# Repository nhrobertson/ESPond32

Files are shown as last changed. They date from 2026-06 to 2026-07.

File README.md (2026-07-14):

# ESPond32

A custom, self-hosted pond control system. An ESP32-S3 unit drives two pumps, a
water-fill valve, and a light, monitors pond water level with a float sensor, and is
controlled from a small web dashboard running on a Raspberry Pi over the local network.
It is the spiritual successor to the earlier, much simpler PondPi.

The device has no on-board web UI by design. All remote control happens over MQTT
between the firmware and the home server; the physical unit is fully functional on its
own (schedules, switches, leak lockout) even with the network down.

## System overview

```
  3-position switches          Raspberry Pi 3
  float sensor          WiFi   +-----------------------+
        |                LAN   | Mosquitto (MQTT broker)|
   +----v-----------+   <----> | espond-home-server     |  <-- browser
   | ESP32-S3 unit  |   MQTT   | (FastAPI dashboard)    |      (LAN / HTTPS)
   | (firmware)     |          +-----------------------+
   +----+-----------+
        | 3V3 GPIO
   +----v-----------+
   | SSR / relay    | ---> mains ---> pumps, valve, light
   +----------------+
```

- The firmware resolves output state from a strict precedence chain: leak lockout >
  physical switch > network override > schedule.
- The home server is the durable source of truth for configuration and schedules; the
  device only stores the last-applied config version.
- The MQTT wire contract between the two is documented in
  `software/espond-home-server/SPEC.md`.

## Repository layout

| Path | What it is |
|---|---|
| `software/espond32/` | Device firmware (ESP-IDF, C). See its README. |
| `software/espond-home-server/` | Raspberry Pi web dashboard + MQTT bridge (Python/FastAPI). See its README. |
| `hardware/` | KiCad projects (on-board and off-board SSR variants), BOMs, datasheets. See its README. |
| `ai_design_doc.pdf` | Original "Pond Control Unit — Design & Build Plan." Guidelines only; see disclosure below. |
| `LICENSE.md` | GNU GPL v3. |

## How this project was built (disclosure)

This repository mixes hand-written and AI-generated work, and it matters which is which:

- The **firmware** (`software/espond32/`) and the **hardware** (`hardware/`) were designed
  and written by hand by the project owner, with only minimal AI assistance.
- The **home server** (`software/espond-home-server/`) was generated almost entirely by an
  AI coding agent (Claude Code) working from a hand-authored spec. It has been deployed and
  works well, but should be reviewed like any AI-written code — particularly the auth and
  MQTT-handling paths — before being exposed beyond a trusted home LAN.
- `ai_design_doc.pdf` was an early planning document. It is **not** an accurate description
  of how the device actually works today; it is kept for historical context only. Where it
  conflicts with the firmware or `SPEC.md`, the firmware and `SPEC.md` win.

## Status

The off-board SSR hardware variant is finalized and in manufacturing. The firmware runs on
ESP32-S3 (developed/validated on a DevKitC). The home server is deployed on a Raspberry Pi 3.

## Safety

This system switches mains-voltage loads. Mains wiring, fusing, and enclosure work are the
integrator's responsibility. The float-fill and leak-lockout logic are failsafes, not
substitutes for correct plumbing, a hardware overflow path, and proper electrical practice.
Do not connect this to mains and water without understanding the whole chain.

## License

GNU General Public License v3. See `LICENSE.md`.

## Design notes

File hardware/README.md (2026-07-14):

# ESPond32 Hardware

KiCad projects and supporting documents for the ESPond32 control board. The board carries
the ESP32-S3-WROOM-1 module, per-channel 3-position switches, the float-sensor input, a
WS2812 status LED chain, and the output-driver stage for four channels (pump1, pump2,
valve1, light1).

Designed by hand with only minimal AI assistance.

## Two board variants

There are two KiCad projects under `kicad/`, differing only in how the mains load is
switched:

| Project | Output stage | Mains on board? | Status |
|---|---|---|---|
| `kicad/espond32-offboard-ssr/` | 3.3V/5V logic-level control signal to an **external** SSR / relay module, driven through a MOSFET buffer | No - board is entirely SELV/low-voltage | **Finalized, in manufacturing** |
| `kicad/espond32-onboard-ssr/` | On-board optotriac + power triac SSR stage, mains terminals on the PCB | Yes | Design variant / reference |

The off-board variant is the primary build. It keeps all mains wiring off the PCB (each
channel just sinks an external module's control line to ground), which greatly simplifies
safety, layout, and enclosure work. The on-board variant is kept for anyone who wants a
single-board solution and is comfortable with mains-on-PCB design; it carries fuse, MOV,
isolated AC-DC, and per-channel triac + snubber parts.

Both variants match the firmware exactly: four output channels (not three), the WS2812 LED
chain on GPIO10, and the switch/float pin map from the firmware's `config.h`.

## Folder layout

```
hardware/
  kicad/
    espond32-offboard-ssr/   # primary board - schematic, PCB, exported BOM/CPL, JLCPCB output
    espond32-onboard-ssr/    # on-board-SSR variant
  bom/                       # STALE - see below
  datasheets/                # ESP32-S3-WROOM-1 datasheet
```

## Bill of materials

**The `bom/` folder at the top level is stale. Do not order from it.** The authoritative BOM
for each board is the one exported from its KiCad project (the `.csv` files inside each
`kicad/espond32-*/` directory, and the `jlcpcb/` outputs for the off-board variant). Treat
the KiCad project as the single source of truth for parts, footprints, and designators; the
top-level `bom/` CSVs predate the current schematics and are kept only for reference.

Key part choices worth knowing before a re-spin (from the current design):

- **Module:** ESP32-S3-WROOM-1-**N8** specifically (quad flash, no PSRAM). The N8R8/N16R8
  PSRAM variants use GPIO33-37, which collide with the firmware's debug test points.
- **Off-board output stage:** logic-level N-channel MOSFET (e.g. 2N7000) per channel buffers
  the GPIO up to a full logic swing before it reaches the external SSR/relay module, so the
  design works with the widest range of off-the-shelf 3-32 VDC modules. The external SSR
  modules themselves are not part of the board BOM.
- **Switches:** one 3-position center-off (ON/AUTO/OFF) toggle per channel; common to 3V3,
  the two throws to the SW-A/SW-B GPIOs. No external pulls (firmware configures pull-downs).
- **Float input:** TVS + series resistor + RC filter, sized for a long outdoor sensor run.
- **Indicators:** a single 6-pixel WS2812B chain (pump1, pump2, valve1, light1, float, sys),
  not discrete LEDs.

## KiCad libraries

The ESP32-S3-WROOM-1 symbol/footprint come from Espressif's official KiCad library
(install via KiCad's Plugin & Content Manager). Standard passives use the built-in KiCad
libraries. A few parts (3-position switch, some connectors) use custom footprints built from
their datasheets - see the project's footprint library.

## Manufacturing (off-board variant)

The `kicad/espond32-offboard-ssr/jlcpcb/` directory holds the Gerber/BOM/CPL output prepared
for JLCPCB assembly. Regenerate it from KiCad if you change the board; do not hand-edit the
exported files.

## Safety

The off-board board is low-voltage only and safe to handle and power from USB-C or a 5V
supply. Mains switching happens entirely in the external SSR modules and their wiring
harness - fusing, strain relief, and enclosure/creepage are the integrator's responsibility.

The on-board-SSR variant puts mains on the PCB and is only for people competent with
mains-voltage design: verify fuse rating, MOV placement, isolation/creepage clearances, and
snubber sizing against your actual loads before powering it.

## Provenance and disclosure

This hardware was designed by hand with minimal AI assistance. Note that `ai_design_doc.pdf`
(repo root) is an early planning document - it specifies three output channels and discrete
indicator LEDs, whereas the shipping design has four channels and a WS2812 chain to match the
firmware. Where the design doc and the KiCad projects disagree, the KiCad projects are
correct.

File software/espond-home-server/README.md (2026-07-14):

# ESPond32 Home Server

Web control panel for the ESPond32 pond controller. Runs on a Raspberry Pi 3, talks to the
device exclusively over MQTT per `SPEC.md`, and is the durable source of truth for the
device's configuration. There is no on-device UI - this is the only dashboard.

## Provenance and disclosure

The ESPond32 **firmware** (`../espond32`) and **hardware** (`../../hardware`) were written by
hand by the project owner with minimal AI assistance. `SPEC.md` is an AI-derived contract: it
was produced by auditing the firmware's actual on-wire MQTT behavior, so it reflects what the
device really does rather than the earlier `ai_design_doc.pdf` design notes.

Everything else in this directory - the entire home server application, its tests, and its
deployment configuration - was produced **almost entirely by an AI coding agent (Claude
Code)** working from `SPEC.md`, with a human reviewing and approving the plan before
implementation but not hand-writing the code. It has been deployed and works well. Treat it
accordingly: review it (especially the auth and MQTT-handling paths) before relying on it for
anything beyond a home LAN.

## Features

- **Dashboard** - live per-output state (pump1, pump2, valve1, light1) plus the float-sensor
  reading and leak-lockout status, streamed to the browser over server-sent events.
- **Overrides** - force any output ON / AUTO / OFF (honored by the device only while its
  physical switch is in AUTO).
- **Schedule editor** - edit the daily on/off times, weekday mask, and float-sensor
  parameters, validated against `SPEC.md` before publishing.
- **Commands** - clear leak lockout, request an immediate status, reboot the device, and
  resend the current config.
- **Settings** - change the admin password and the MQTT broker connection.
- **Auth** - single admin password (bcrypt-hashed), signed session cookie, and login
  attempt lockout.

The server keeps the full config document and the last version number it pushed, and
version-increments on every change, since the device only accepts strictly-newer configs and
cannot be asked to read its config back (see `SPEC.md` §5).

## Local development

```bash
python3 -m venv .venv
.venv/bin/pip install -r requirements.txt
.venv/bin/pytest tests/           # unit tests, no broker needed
```

Run the app (needs a reachable MQTT broker - see below for a local Mosquitto, or just let it
start without one; it retries the connection in the background):

```bash
# ESPOND_COOKIE_SECURE=false is only for http:// local dev; omit it in production (Caddy/HTTPS)
ESPOND_COOKIE_SECURE=false .venv/bin/uvicorn app.main:app --reload --host 127.0.0.1 --port 8000
```

Open http://127.0.0.1:8000 - first visit prompts you to set the admin password.

### Exercising the full flow without real hardware

Run a local Mosquitto broker, then in another terminal:

```bash
.venv/bin/python tools/mock_device.py --host localhost --username espond --password password
```

`mock_device.py` plays the firmware's role (accepts config, responds to `pond/cmd`, resolves
overrides, publishes status) so you can drive the dashboard/schedule editor end-to-end. Type
`leak on`/`float on`/`reboot` at its prompt to test those states.

## Deployment (Raspberry Pi)

See `deploy/setup.sh` for a scripted bring-up (Mosquitto + this app under systemd + Caddy for
automatic HTTPS). Summary:

1. Copy this project to `/opt/espond-home-server` on the Pi.
2. `sudo bash deploy/setup.sh` - installs Mosquitto/Caddy, creates the venv, installs the
   systemd unit.
3. Point a domain/DDNS name at your home IP, edit `/etc/caddy/Caddyfile`, forward
   ports 443/80 on your router.
4. Point the ESP32 firmware's broker URI (`components/network/network.c` in the firmware
   project) at this Pi's LAN IP, with matching Mosquitto credentials.

The admin panel is reachable from the internet once port forwarding is live - that is why
setup routes everything through Caddy's automatic HTTPS rather than serving plain HTTP.

## Configuration

Broker host/port/credentials are stored in the database and editable at `/settings`; the
`ESPOND_MQTT_*` environment variables only seed the defaults on first run. Other environment
variables: `ESPOND_DB_PATH`, `ESPOND_SESSION_MAX_AGE`, `ESPOND_COOKIE_SECURE`.

## Project layout

- `app/` - FastAPI application
  - `mqtt_client.py` - MQTT wire-contract implementation (publish config/override/cmd, parse status)
  - `routes/` - dashboard, schedule, settings, auth, and the SSE `events` stream
  - `state.py` - in-memory device state fed from `pond/status` / `pond/availability`
  - `validators.py` - `SPEC.md` §3 payload validation
  - `db.py`, `models.py`, `auth.py`, `settings.py` - storage, schemas, auth, config
  - `templates/`, `static/` - server-rendered UI
- `deploy/` - systemd unit, Mosquitto config, Caddyfile, bring-up script
- `tools/mock_device.py` - firmware simulator for local testing
- `tests/` - unit tests (validators, MQTT payload shapes, auth)
- `SPEC.md` - authoritative MQTT wire contract (source of truth over `ai_design_doc.pdf`)

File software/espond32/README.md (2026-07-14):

# ESPond32 Firmware

Firmware for the ESPond32 pond control unit. Targets the **ESP32-S3-WROOM-1 (N8)** and
builds as a standard ESP-IDF project. It drives two pumps, a water-fill valve, and a light
through external solid-state relays, monitors pond level with a float sensor, and is
controlled remotely over MQTT by the home server (`../espond-home-server`).

Written by hand in C with only minimal AI assistance used for minor debugging and heavy review. Committed under the GNU GPL v3.

## What it does

- Runs each output (pump1, pump2, valve1, light1) on a weekday-aware daily schedule.
- Resolves the real output state through a fixed precedence chain (highest wins):
  1. **Leak lockout** - forces pumps and valve off; survives reboot (persisted in NVS).
  2. **Physical 3-position switch** - ON / AUTO / OFF per channel; a thrown switch beats
     any network override.
  3. **Network override** - `pond/override` from the server, honored only while the switch
     is in AUTO.
  4. **Schedule** - the configured on/off/days, honored only when switch and override are
     both AUTO.
- Automatically fills the pond via `valve1` when the float sensor reads dry, with a
  configurable arming debounce and overflow timeout, and a daily fill-count cap.
- Engages leak lockout when the pond fills too many times in a day or a single fill runs
  too long (stuck-float failsafe), and requires an explicit clear (server command or a 5s
  physical reset-button hold) to recover.
- Reports state to the server over MQTT and drives a WS2812 status LED chain.

Precedence and float behavior are the safety-critical parts of the design and are the
reason there is no on-device web UI: the unit keeps running correctly with the network down.

## Architecture

Devices are unified behind a small polymorphic interface (`device_t` / `device_ops_t`) so
pumps, valve, light, and the float sensor share one code path. Work is split across
FreeRTOS tasks pinned to the two cores:

| Task | Core | Cadence | Role |
|---|---|---|---|
| `task_check_io` | 1 | 10 ms | Debounce switches + float sensor |
| `task_evaluate_cfg` | 1 | 250 ms | Resolve schedule/override/lockout precedence |
| `task_operate` | 1 | 50 ms | Apply resolved state to SSR GPIOs |
| `task_check_leak` | 1 | 10 ms | Float-fill state machine + leak detection |
| `task_check_for_reset` | 1 | 50 ms | Reset-button hold detection |
| `task_listen_for_task_event` | 1 | event | Handle clear-leak / command events |
| `task_set_sys_light` | 1 | 1 s | System status LED |
| `task_check_cfg` | 0 | event | Apply new config (double-buffered swap) |
| `task_net_manager` | 0 | event | WiFi + MQTT lifecycle |

Config is double-buffered: the MQTT task writes into a staging buffer, and `task_check_cfg`
atomically swaps it into the live config under a mutex. Config is version-gated and
persisted to NVS, so it survives reboots and only newer versions are applied.

### Components

| Component | Responsibility |
|---|---|
| `config/` | Pin map, device counts, timing constants, debug GPIOs |
| `models/` | Shared types, enums, JSON builders, RTOS handles |
| `device/` | Device abstraction + state resolution |
| `io/` | GPIO configure/set, software debounce, reset button |
| `float/` | Float-fill state machine and leak logic |
| `led/` | WS2812 status LED driver |
| `date_and_time/` | SNTP time + schedule evaluation (handles overnight wrap) |
| `filesystem/` | NVS persistence (config version, leak lockout) |
| `network/` | WiFi STA, MQTT client, config parse, status publish |
| `tasks/` | The FreeRTOS task bodies listed above |

## Pin map

Defined in `components/config/include/config.h`. Each output uses two switch inputs plus one
SSR output; the float sensor is a single input; one GPIO drives the WS2812 chain.

| Function | GPIO |
|---|---|
| Pump1 SSR / SW-A / SW-B | 4 / 5 / 6 |
| Pump2 SSR / SW-A / SW-B | 7 / 15 / 16 |
| Valve1 SSR / SW-A / SW-B | 17 / 18 / 8 |
| Light1 SSR / SW-A / SW-B | 11 / 12 / 13 |
| Float sensor | 9 |
| WS2812 data | 10 |
| Reset / leak-clear button | 14 |

GPIO35-38 are used as task-timing debug test points (`DEBUG_GPIO_*`), which is why the
module **must** be the N8 (no-PSRAM) variant - the PSRAM variants use those pins internally.
The switch inputs are configured pull-down and the reset button pull-up, so no external pull
resistors are needed.

## MQTT interface

The device connects to one broker and speaks the contract in
`../espond-home-server/SPEC.md`. Summary of topics:

| Topic | Direction | Purpose |
|---|---|---|
| `pond/config` | server -> device | Full config (version-gated, all 4 outputs + float params) |
| `pond/override` | server -> device | Force a single output ON/AUTO/OFF |
| `pond/cmd` | server -> device | `clear_leak_lockout` / `reboot` / `request_status` |
| `pond/status` | device -> server | Retained state of all 4 outputs + float reading |
| `pond/availability` | device -> server | Retained `online`/`offline` (MQTT Last-Will) |

Single-device assumption: topics are fixed global strings, not namespaced per unit.

## Build and flash

Requires ESP-IDF (v4.1+; developed on a recent v5.x). Managed components (`led_strip`,
`cjson`, `mqtt`) resolve automatically via the component manager.

```bash
idf.py set-target esp32s3
idf.py build
idf.py -p /dev/ttyACM0 flash monitor
```

## Configuration you must change before flashing (disclosure)

`components/network/network.c` currently contains **hardcoded placeholder credentials** that
need to be replaced for your environment before deployment:

- WiFi SSID and password.
- MQTT broker URI (point it at your Raspberry Pi / Mosquitto LAN IP).
- MQTT client id / username / password (must match the broker's credentials).

MQTT is plaintext (no TLS) and the broker auth is a single username/password. This is
acceptable for a trusted home LAN but should be hardened before the device is reachable from
anywhere less trusted. Do not commit real WiFi/broker secrets.

## Provenance and disclosure

- This firmware was written by hand; AI assistance was minimal.
- `IMPLEMENTATION_STATUS.md` in this directory is a **historical AI-generated audit** from an
  earlier revision. It documented bugs that were subsequently addressed and does not describe
  the current state of the code - read it as a snapshot, not as current documentation.
- `SPEC.md` (in the home-server directory) was derived by auditing this firmware's actual
  on-wire behavior, so it reflects what the device really does. The older `ai_design_doc.pdf`
  is guidelines only and is superseded wherever it conflicts.

## License

GNU General Public License v3. See `../../LICENSE.md`.

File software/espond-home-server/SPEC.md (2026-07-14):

# ESPond32 Home Server — Network Interaction Spec

Version 0.1 — derived directly from the current ESPond32 firmware (`../espond32`), not from
`ai_design_doc.pdf`. The firmware's actual on-wire behavior is now the source of truth for this
contract; the design doc's original §8/§9 examples (weekday-string `days`, `"id"`-keyed outputs,
a `"float"` config key) are superseded and should be ignored where they conflict with this
document.

This spec covers only the **network interaction contract** between the home server and one
ESPond32 unit. It does not cover the server's own UI, storage schema, or scheduling algorithms —
those are implementation details of the home server itself.

## 1. Scope & deployment target

- The home server is a service intended to run on a **Raspberry Pi 3**, reached over the same
  **WiFi LAN** as the ESPond32 device. No wired/Ethernet assumption.
- All device interaction happens over **MQTT**. There is no HTTP/REST/webpage on the device
  itself (the design doc explicitly rejected an on-device web UI in favor of MQTT + a home
  server).
- The firmware connects to a single hardcoded broker URI (`network.c`: `mqtt_cfg.broker.address.uri`,
  currently the placeholder `"mqtt://IP_ADDR"`). **Something has to run a broker** (e.g.
  Mosquitto) reachable at that address. The simplest deployment is to run the broker on the same
  Raspberry Pi as the home server and point the firmware's placeholder URI at the Pi's LAN IP —
  but this is a deployment decision, not something the firmware enforces.
- MQTT is currently **plaintext, unauthenticated at the broker level** beyond a username/password
  pair (`network.c`: client id `"espondcu"`, username `"espond"`, password `"password"` — all
  placeholders). No TLS. The home server should use the same broker credentials scheme; treat
  this as "expected to be hardened later," not something to over-engineer around today.
- **Single-device assumption.** Every topic below is a fixed global string (`pond/...`), not
  namespaced by device ID. The firmware does not support multiple ESPond32 units sharing one
  broker without a firmware change (topic namespacing). Build the server for exactly one device
  for now.

## 2. Topics

| Topic | Direction | QoS | Retained | Payload |
|---|---|---|---|---|
| `pond/config` | server → device | 1 | no | JSON, §3.1 |
| `pond/cmd` | server → device | 1 | no | raw string, §3.2 |
| `pond/override` | server → device | 1 | no | JSON, §3.3 |
| `pond/status` | device → server | 1 | **yes** | JSON, §3.4 |
| `pond/availability` | device → server | 1 | **yes** | `"online"` / `"offline"` (LWT), §3.5 |

The device subscribes to the first three on every MQTT connect and does not persist an MQTT
session across reconnects — the server should assume a fresh subscribe happens each time the
device reconnects, and should be prepared to re-deliver `pond/config` if it suspects the device
missed it (see §6).

## 3. Message schemas

### 3.1 `pond/config` (server → device)

```json
{
  "version": 4,
  "outputs": [
    { "name": "pump1",  "on": "14:00", "off": "14:05", "days": [0,1,2,3,4,5,6] },
    { "name": "pump2",  "on": "14:00", "off": "14:05", "days": [0,1,2,3,4,5,6] },
    { "name": "valve1", "on": null,    "off": null,    "days": [] },
    { "name": "light1", "on": "18:00", "off": "23:00", "days": [5,6] }
  ],
  "float_sens": { "threshold_min": 10, "overflow_min": 30, "max_fills_per_day": 3 }
}
```

Field rules (enforced by `parse_config_json` — any violation causes the **entire message to be
rejected**, with no partial apply and no error reported back to the server over MQTT):

- `version`: integer. The device only accepts a config if `version` is **strictly greater** than
  its currently stored version (persisted in NVS, survives reboot). The server must track the
  last version it successfully pushed and always increment before pushing a change. There is no
  way to query the device's currently-applied version except via `pond/status` (see §3.4) —
  the server is the source of truth for "what config is on the device," not the other way around
  (see §6, known limitation).
- `outputs`: array, up to 4 entries. Each entry is matched **by `"name"`, not position or an
  `"id"` field** — must be exactly one of `"pump1"`, `"pump2"`, `"valve1"`, `"light1"`. Unknown
  names are rejected (whole message fails). If an expected device name is *missing* from the
  array, that device silently keeps a fully-off, never-scheduled state — the firmware treats an
  absent entry as "no schedule" rather than erroring, so a partial `outputs` array won't crash
  anything, but it also won't preserve whatever schedule was previously set for the omitted
  device. Always send all 4 entries.
- `on` / `off`: `"HH:MM"` 24-hour strings, or both `null` together to mean "no schedule" (device
  only reachable via `pond/override` or the physical switch, never turns on by schedule).
  Sending only one of the two as `null` is invalid and rejects the message.
- `days`: array of integers **0–6** (Sunday=0 through Saturday=6, matching C `tm_wday` — **not**
  weekday abbreviation strings). Empty array is valid (means "no day is scheduled," equivalent in
  effect to a null on/off). Any value outside 0–6 rejects the whole message.
- `float_sens.threshold_min`: minutes the float sensor must continuously read "low" (float out
  of the water) before the device treats it as a genuine low level and opens `valve1` to fill
  (debounces brief dips from waves/ripples). Note the sensor polarity: the float line idles high
  and closes to ground when the float is submerged, so `pond/status` reports `float1.state=true`
  when the water is **low / a fill is wanted**, not when it is wet — see §3.4.
- `float_sens.overflow_min`: minutes after the sensor reads "not low" again (float back in the
  water) before the fill is considered fully finished (closes out the fill cycle / daily fill
  count).
- `float_sens.max_fills_per_day`: if the number of completed fill cycles in the current calendar
  day exceeds this, the device engages **leak lockout** (see §4) — forces `pump1`, `pump2`, and
  `valve1` off regardless of schedule or override, until explicitly cleared.

There is no partial-update semantics — every push must include the full desired state for all
4 outputs and all 3 float-sensor parameters. The server should keep this full config resident and
always send a complete document.

### 3.2 `pond/cmd` (server → device)

Plain string payload, **not JSON**. Exactly one of:

| Payload | Effect |
|---|---|
| `clear_leak_lockout` | Clears leak lockout: resets `lockout` state (RAM + NVS) and the daily fill counter. Devices return to normal schedule/override/switch resolution on the next evaluate cycle (≤250ms). |
| `reboot` | Immediate `esp_restart()`. No graceful shutdown, no ack. |
| `request_status` | Forces an immediate `pond/status` publish (see §3.4), independent of whether anything changed. |

Any other string is silently ignored — no error is published back.

### 3.3 `pond/override` (server → device)

```json
{ "name": "pump1", "override": 0 }
```

- `name`: one of `"pump1"`, `"pump2"`, `"valve1"`, `"light1"`. `"float1"` is rejected — the float
  sensor is input-only and cannot be overridden.
- `override`: integer, one of:

  | Value | Meaning |
  |---|---|
  | `0` | Force **ON** |
  | `1` | Release to **AUTO** (schedule decides) |
  | `2` | Force **OFF** |

  Any other integer is accepted by the parser but silently treated as `1` (AUTO) — there is no
  rejection for an out-of-range override value, unlike the other message types.

An override only takes effect while that device's **physical 3-position switch is in the AUTO
position** — see precedence in §4. There is no way to know from the network side alone whether an
override is currently "winning" versus being shadowed by the physical switch; `pond/status`
reports the resulting `state` (on/off) but not *why* it's in that state.

### 3.4 `pond/status` (device → server, retained)

```json
{
  "version": 4,
  "leak_lockout": false,
  "outputs": [
    { "name": "pump1",  "state": true },
    { "name": "pump2",  "state": false },
    { "name": "valve1", "state": false },
    { "name": "light1", "state": true },
    { "name": "float1", "state": false }
  ]
}
```

- Despite the key being `"outputs"`, this array always has **5** entries, not 4 — `"float1"` is
  included and its `"state"` is an input reading, not an output being driven. `float1.state=true`
  means the **float is out of the water (level LOW, a fill is wanted)**; `false` means the water
  is up. This follows the firmware's sensor polarity (idle-high line pulled to ground when the
  float is submerged) — do not read `true` as "wet." The server must not treat all 5 entries
  uniformly if it plans to expose actuator-only controls.
- `"state"` is the *actual* on/off/active state after all precedence resolution (leak lockout,
  switch, override, schedule) — it is the only place the server can observe the real-world
  outcome of a config or override push.
- Published only when something changes (a device's on/off state flips, leak lockout engages) or
  when explicitly requested via `pond/cmd` → `request_status`. **It is not published on a
  periodic heartbeat**, and it is not automatically (re-)published just because the server
  reconnects to the broker — only the *retained* copy from the last publish is delivered on
  subscribe. If the server needs current truth right after startup/reconnect, send
  `request_status` rather than trusting the retained value blindly (the device could have
  rebooted, or its state could have changed while the broker was unreachable to the retained
  message... though MQTT retained messages do survive broker restarts if persistence is enabled -
  the risk is specifically a *device*-side change with no observer connected to receive it live).

### 3.5 `pond/availability` (device → server, retained, Last Will)

Payload is the literal string `"online"` (published once, on every successful MQTT connect) or
`"offline"` (published automatically **by the broker**, not the device, as the MQTT Last-Will
message if the device disconnects without a clean shutdown — e.g. power loss, WiFi drop, crash).
The server should treat `"offline"` (or the topic simply never having been set) as "device
presence unknown," and should not assume the device's last known `pond/status` is still accurate
once availability drops to offline.

## 4. Precedence model the server must respect

For `pump1`, `pump2`, `valve1` (light1 is the same minus the lockout tier):

1. **Leak lockout** (if engaged) — forces OFF. Beats everything, including a manual override.
   Only `pond/cmd` → `clear_leak_lockout`, or a 5-second physical reset-button hold on the
   device, can lift it.
2. **Physical 3-position switch** — if held to the ON or OFF side (not centered/AUTO), that wins
   over any `pond/override` sent by the server. The server has no way to detect switch position
   directly; it can only infer "my override doesn't seem to be taking effect" from `pond/status`
   not matching what was requested.
3. **`pond/override`** (server command) — only consulted when the switch is centered/AUTO.
4. **Schedule** (`pond/config` on/off/days) — only consulted when both switch and override are
   AUTO.

Implication for the server: don't build a UI that assumes a command always "wins" — always treat
`pond/status` as the arbiter of truth, and design any "why didn't my change apply" UX around the
possibility of the physical switch overriding it silently.

## 5. Known limitations / open items for the server design

- **No config read-back.** The device cannot be asked "what config do you currently have
  applied?" beyond the bare `version` number in `pond/status`. The server must be the durable
  store of the full config document and must not assume it can reconstruct it from the device.
- **No per-command acknowledgment.** Every `pond/cmd`/`pond/override`/`pond/config` message is
  fire-and-forget; success or failure is only observable indirectly through a later
  `pond/status` change (or its absence).
- **No malformed-message feedback.** A rejected `pond/config` (bad version, bad name, out-of-range
  day, etc.) fails silently on the device side — no error topic, no NACK. The server should
  validate against §3.1's rules itself before publishing, since the device won't tell it what
  went wrong.
- **Single device, unauthenticated broker, plaintext transport** — acceptable for a bench/home
  LAN today; flag before this is ever exposed beyond a trusted local network.
- **Broker location is undecided** — this spec assumes *a* broker exists at whatever URI the
  firmware is flashed with; deciding whether that's Mosquitto on the same Pi as the server or a
  separate box is a deployment decision for whoever sets up the Pi, not a firmware or server
  constraint.

## 6. Suggested server responsibilities (non-normative)

Not part of the wire contract, but worth the server implementation keeping in mind:

- Persist the full last-pushed `espond_cfg_t`-equivalent document and the last version number
  used, so a server restart doesn't lose track of what's supposedly on the device.
- On startup / broker reconnect, subscribe to `pond/status` and `pond/availability`, then send
  `request_status` once availability shows `"online"`, rather than trusting a stale retained
  status.
- Treat `pond/status`'s 5-entry array as the single source of "what is actually happening right
  now" for any dashboard, rather than mirroring back whatever config/override was last sent.

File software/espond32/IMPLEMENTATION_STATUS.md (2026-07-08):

# ESPond32 — Implementation Status Evaluation

_Evaluation of firmware vs. the design doc (`../../ai_design_doc.pdf`, "Pond Control Unit — Design & Build Plan"). Date: 2026-07-07. No code was modified to produce this — full read-through of every `.c`/`.h` file in `main/` and `components/`._

## Overall status

The architecture and most of the parsing/scheduling logic are well-reasoned and track the design doc closely: a device abstraction unifying pumps/valve/light/float behind one polymorphic `device_ops_t` interface, FreeRTOS tasks that split cleanly along the doc's lines (input check / config apply / schedule+precedence resolve / operate / leak / net), NVS-backed JSON config with version gating, and an MQTT sync layer with retained topics and Last-Will.

That said, **this is not "almost done."** A full read of every source file turned up several bugs that would prevent correct operation if flashed today — including bugs very likely to crash on first boot, and one that defeats the design doc's single most important correctness rule (leak lockout must force outputs off). This reads as **mid-Phase-3/4 firmware in progress**, not a working autonomous controller. The hardware/PCB (design doc phases 6–10), home server (phase 11), and enclosure (phase 12) are entirely out of scope for this repo and not evaluated here.

## Firmware, phase by phase (design doc §14)

| Phase | Status | Notes |
|---|---|---|
| 0 — Toolchain | Done | ESP-IDF project targets `esp32s3`; managed components (cJSON, esp-mqtt, led_strip) resolve; project builds as a normal IDF tree. |
| 1 — Bare I/O | Mostly done | GPIO configure/read/set, majority-count software debounce, and the WS2812 LED driver init all exist and are structurally sound — but see LED bug below: nothing is ever actually pushed to the physical strip. |
| 2 — Timekeeping | Mostly done | SNTP is started and a timezone (`EST5EDT,M3.2.0,M11.1.0`) is set in `network.c`, addressing the exact drift bug the redesign was meant to fix. `get_local_time()` exists and is used by both the scheduler and the leak/float logic. No DS3231/RTC (called out as optional in the doc). |
| 3 — Scheduler + Output manager | Implemented, but the safety-critical path is broken | `evaluate_device_schedule()` correctly handles overnight wraparound and per-weekday masking. `resolve_device_state()` implements the switch/override precedence. **But** the leak-lockout tier silently disables the entire resolver instead of forcing outputs off — see Critical Bug #2. |
| 4 — Float-fill + leak | Implemented, with two logic bugs | State machine (idle → arming → filling → overflow) exists and daily fill counting/latching exists, but the configurable `threshold_min` debounce is never applied (Critical Bug #6) and the MQTT "clear leak lockout" command doesn't actually clear the lockout (Critical Bug #7). |
| 5 — Connectivity | Implemented, least-hardened area | WiFi STA, MQTT with Last-Will, version-gated config → NVS persistence, exponential backoff reconnect, and status publishing all exist. Credentials are still hardcoded placeholders (`"ssid"`, `mqtt://IP_ADDR`) and MQTT is plaintext — expected at this stage. `publish_status` has a memory-corruption bug (Critical Bug #5). |

## Critical bugs (would misbehave or crash on real hardware)

4. **`parse_override_json` corrupts memory and copies the wrong field.** `components/models/models.c:128`:
   ```c
   override_json_t over = { .name = "", .override = OVR_AUTO };
   ...
   strcpy(over.name, name->string);
   ```
   `override_json_t.name` is a `char*` (`models.h:142`) initialized to point at a string literal — `strcpy` into that writes to read-only memory. It also copies `name->string` (the JSON *key*, literally the text `"name"`) instead of `name->valuestring` (the actual device name sent by the server). Any incoming `pond/override` MQTT message will corrupt memory / likely crash, and even if it didn't, would never match a real device name.

5. **`publish_status` has the same class of bug.** `components/network/network.c:165`: `strcpy(devices[i].name, g_devices[i].name)` writes into `devices[i].name`, an uninitialized stack `char*` (`status_json_builder_t.name` is a pointer, not a fixed buffer — `models.h:138`). This runs on every status publish and is effectively guaranteed stack corruption. `g_devices[i].name` should be used directly in the `sniprintf` call below it; the intermediate copy is both unnecessary and broken.

6. **`threshold_min` is parsed but never used — the float-fill "wait before triggering" delay is a no-op.** `eval_float_state` (`components/float/float.c:39`):
   ```c
   case (FILL_IDLE):
     if (active) {
       float_deadline_us = time_us;      // should be time_us + minutes_us(threshold_min)
       dev->u.in.state = FILL_ARMING;
     }
   ```
   The deadline is set to *now*, so on the very next evaluation `time_us >= float_deadline_us` is already true and the valve fires immediately. The configurable debounce period from design-doc §2/§8 (and preserved intentionally from the original PondPi) currently does nothing.

7. **The MQTT "clear leak lockout" command doesn't clear the lockout.** `handle_command_msg` → `task_listen_for_task_event` → `clear_leak()` only resets the daily fill counter (`float.c:11`); it never resets the `lockout` bool or the forced `OVR_OFF` overrides that `task_check_leak` applied. Only the physical 5-second reset-button hold (`tasks.c:39-41`, which also `esp_restart()`s the device) actually clears it. The server-facing command described in design-doc §9 is effectively dead.

8. **Leak lockout state is written to NVS but never read back.** `nvs_set_lockout`/`nvs_clear_lockout` (`components/filesystem/filesystem.c`) persist a `"lockout"` key, but nothing in the tree ever calls `nvs_get_u8` for it — `lockout` always starts `false` on boot regardless of what was persisted before a reset, defeating the point of persisting it. (Partially masked by Bug #2's frozen-state behavior, but the intent — a lockout that survives a power cycle — is broken either way.)

## Secondary issues

- **GPIO interrupts configured but never wired up.** Switches and the float sensor are configured with `GPIO_INTR_HIGH_LEVEL`, and the reset button with `GPIO_INTR_ANYEDGE` (`components/io/io.c:30,104,107,114`), and interrupts are enabled via `gpio_intr_enable` — but `gpio_install_isr_service`/`gpio_isr_handler_add` are never called anywhere. Everything actually works today via 10 ms polling in `task_check_io`, so this is at minimum dead configuration; a level-triggered interrupt enabled with no ISR to service/clear it is also the kind of thing that can trip the interrupt watchdog on real silicon. Either remove it or wire it up properly.
- **`PIX_BLUE` is defined as green.** `components/led/led.c:8`: `const pix_t PIX_BLUE = {.r=0, .g=255, .b=0};` — identical to `PIX_GREEN`. The float-active indicator (`tasks.c:216` uses `PIX_BLUE`) would show green, not blue, once Bug #3 is fixed.
- **`nvs_flash_init()`'s return value is discarded** (`main/espond32.c:41`) — no erase+retry on `ESP_ERR_NVS_NO_FREE_PAGES`/`ESP_ERR_NVS_NEW_VERSION_FOUND`, a common real-world case after reflashing with a different partition layout. A corrupted NVS partition would currently, silently and permanently, prevent config persistence with no self-healing path.
- Dead/unfinished abstractions: `led_state_t` / `get_color()` (declared `static` in `led.h`, never defined or used — LED updates go through raw `pix_t` colors instead of the state machine the types imply); `io_operate()` declared in `io.h` but never defined; `nvs_load_espond_cfg` is file-internal but not marked `static`.
- `#define NUM_LEDS NUM_DEVICES + 2` (`components/config/include/config.h:14`) is unparenthesized — harmless today (only used standalone) but a latent bug if it's ever combined with an operator at a use site.
- Hardcoded placeholder WiFi/MQTT credentials and plaintext (non-TLS) MQTT in `network.c` — expected at this stage, flagged only so it isn't forgotten before anything leaves the bench.

## What's solid

- The `device_t`/`device_ops_t` polymorphic abstraction cleanly unifies pumps/valve/light/float behind one interface and matches the design doc's intent well.
- `evaluate_device_schedule()` (`date_and_time.c`) correctly handles overnight (`on_min > off_min`) wraparound schedules and per-weekday masking — genuinely correct logic.
- `parse_config_json()` is careful and defensive: `goto cleanup` on every malformed field, `strlcpy` for names, explicit range checks in `parse_hhmm`.
- The debounce implementation in `io.c` is a reasonable simple majority-count debounce.
- The MQTT topic layout (`pond/config`, `pond/status`, `pond/availability`, `pond/cmd`, plus an added `pond/override` not in the doc) matches design-doc §9 closely, with retained messages and Last-Will wired correctly.
- Config double-buffering (`g_buff_cfg` written by the MQTT task, atomically swapped into `g_espond_cfg` under `cfg_change_mutex` by `task_check_cfg`) is a sound pattern for cross-core, cross-task config updates.

## Bottom line

The plumbing and the "shape" of the system are close to the design doc and mostly well-structured. But between a near-certain boot-time crash (Bug #1), two memory-corruption bugs on incoming/outgoing MQTT traffic (Bugs #4, #5), a dead LED subsystem (Bug #3), and — most importantly — a leak lockout that doesn't actually cut power (Bug #2), this needs a focused debugging pass before it's safe to move on to phase 6 (prototype circuit) or trust it near mains and water at all.

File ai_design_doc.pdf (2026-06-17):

# Pond Control Unit

## An ESP32-S3 reimagining of PondPi — design & build plan

A from-scratch redesign of a backyard-pond pump and water-fill controller. The unit runs autonomous scheduling firmware on an ESP32-S3 under ESP-IDF, is configured from a separate home-server admin panel, and is built around a single integrated PCB that brings mains power, isolated logic, and three on-board triac solid-state-relay channels onto one board.

Design document · synthesized from project planning
Original concept: PondPi by Noah Robertson (MIT) · github.com/nhrobertson/PondPi
Pond Control Unit — Design & Build Plan | Page 1 of 20

## Contents

### 1. Overview

### 2. Background: the original PondPi

### 3. Design decisions

### 4. System architecture

### 5. Hardware requirements

### 6. Firmware architecture

### 7. Output precedence logic

### 8. Configuration model

### 9. Sync protocol & timekeeping

### 10. ESP-IDF project structure

### 11. Home server

### 12. PCB design

### 13. Indicative bill of materials

### 14. Plan of attack

### 15. Safety notice

### 16. Appendix: pin budget & references

## 1 Overview

The Pond Control Unit (PCU) controls two pond pumps and an automatic water-fill valve, with a float sensor for level detection. It replaces the Raspberry Pi Pico W at the heart of the original PondPi project with an ESP32-S3, and splits the system into three tiers: an admin browser, a home server that hosts the configuration panel, and the edge device that does the actual switching.

The defining principle of this redesign is device autonomy. The home server is where schedules are edited, but the ESP32 stores its own copy of the configuration and runs it independently. If the server reboots, the network drops, or the internet is unavailable, the pumps keep running on schedule. The server pushes configuration down; the device reports status up.

The four functional signals are unchanged from the original requirements:

Float sensor — optional 3.3 V input plus an indicator LED.
Pump 1 — 3.3 V output driving an SSR that switches a 120 V pump, plus an LED.
Pump 2 — as Pump 1.
Water fill — 3.3 V output driving an SSR that switches a 120 V electric valve, plus an LED.

Every output additionally has a physical switch that enables or disables that function, and every output has its own LED indicator.

## 2 Background: the original PondPi

PondPi is a single Raspberry Pi Pico W running MicroPython that does everything on one device. Understanding its structure clarifies exactly what is being kept, changed, and fixed.

Module | Role
main.py | Async entry point; initializes timers, loads the web page, connects WiFi, starts the HTTP server and the float/leak monitor tasks.
hw_util.py | GPIO control (outputs on pins 3/4/5, float sensor on pin 18), float-fill logic, leak detection, timer setup.
timer.py | A Timer class that checks every 60 s whether the current hour/minute/day matches and fires a callback.
config_manager.py | Reads/writes an INI-style config.txt for persistence.
network_util.py | WiFi connect and a hand-rolled HTTP server that parses requests and dispatches to enable/disable/set-time handlers.
index.html | The web UI served directly by the device.

Its float logic is worth preserving: when the float sensor stays active past a configurable threshold time, the water-fill output turns on; when the sensor clears, the fill stays on for an overflow time, then shuts off. A leak guard counts fills per day and latches everything off if more than a set number occur in 24 hours, requiring

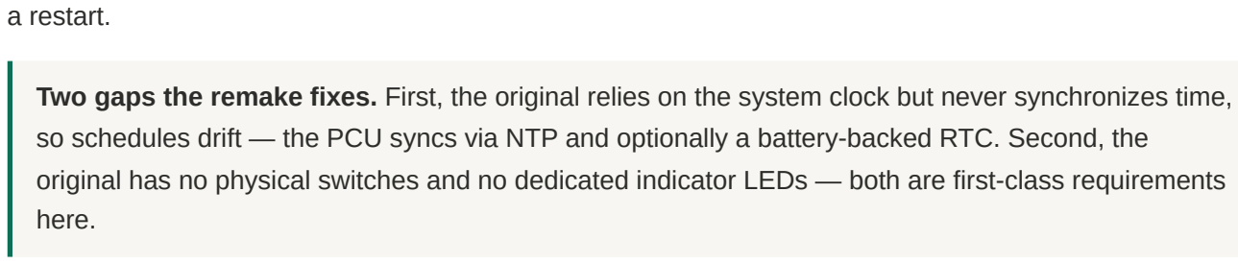
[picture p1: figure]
a restart.; here.

Two gaps the remake fixes. First, the original relies on the system clock but never synchronizes time, so schedules drift — the PCU syncs via NTP and optionally a battery-backed RTC. Second, the original has no physical switches and no dedicated indicator LEDs — both are first-class requirements

## 3 Design decisions

The following choices were made up front; they shape every later section.

Decision | Choice | Rationale
Goal | Fully custom build | Maximum control and learning value; not a low-code/Home-Assistant path.
Firmware stack | ESP-IDF (C) | Native FreeRTOS, fine-grained control of tasks, NVS, drivers, and OTA.
Device autonomy | Autonomous | Device stores and runs its own schedule; survives server/network outages.
Board power | Isolated AC-DC on board | Single mains feed; fully integrated unit. Raises isolation/layout requirements.
Load switching | On-board triac SSRs (opto-triac + triac) | Compact, cheap, true solid-state switching built from discrete parts.
MCU | ESP32-S3 module | Native USB for flashing/JTAG, ample flash/PSRAM, pre-certified RF module.

## 4 System architecture

The system is three tiers. An admin browser talks to the home server over HTTP. The home server syncs configuration and status with the ESP32 over WiFi. The ESP32 reads 3.3 V inputs and drives 3.3 V outputs into solid-state relays that switch the 120 V loads.

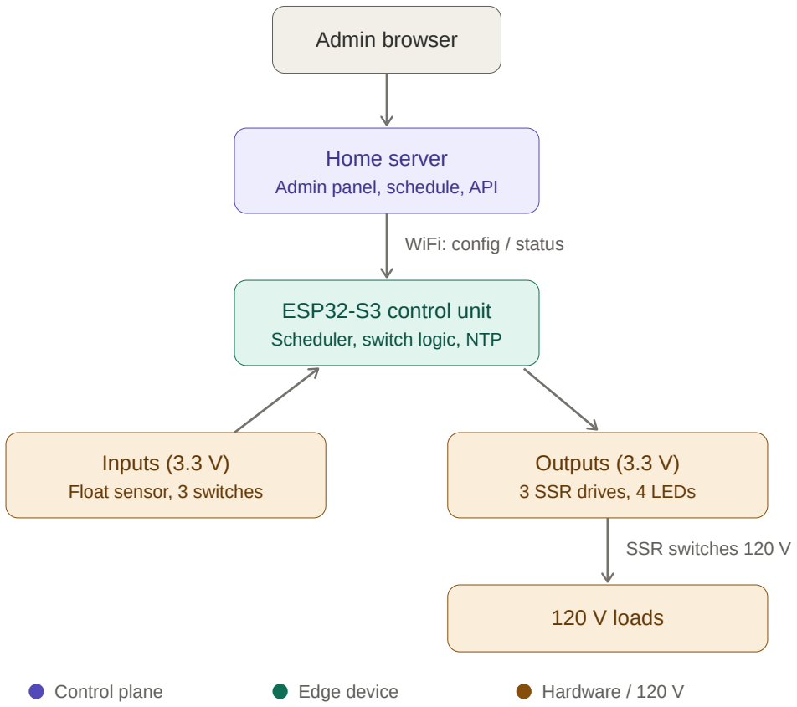
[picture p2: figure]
Admin browser; Home server; Admin panel, schedule, API; WiFi: config / status; ESP32-S3 control unit; Scheduler, switch logic, NTP; Inputs (3.3 V); Float sensor, 3 switches; Outputs (3.3 V); 3 SSR drives, 4 LEDs; SSR switches 120 V; 120 V loads; Control plane; Edge device; Hardware / 120 V

Figure 1 — Three-tier system architecture.

This separates concerns cleanly: the home server owns the human-facing editing experience, while the device owns execution. The only thing crossing the WiFi link is a small configuration blob in one direction and status in the other.

## 5 Hardware requirements

The I/O budget is small — roughly eleven GPIO — so any ESP32 variant suffices; the S3 is chosen for native USB and headroom. The signal set:

Signal | Direction | Notes
Float sensor | Input | Internal pull, software debounce, TVS + series resistor for the long outdoor run.
Switch 1 / 2 / 3 | Input | One 3-position switch per output: ON / OFF / AUTO .
SSR drive 1 / 2 / 3 | Output | 3.3 V logic into the opto-triac LED of each channel.
LED 1 / 2 / 3 | Output | Output-state indicators, driven on the logic side.
Float LED | Output | Sensor-active indicator.

Three-position switches

Rather than a plain on/off toggle, each output gets a 3-position switch. OFF forces the output off (a true safety lockout), ON forces it on (manual override), and AUTO hands control to the firmware schedule. The firmware reads the switch position and always honors it; the indicator LED reflects the resolved state so the panel never lies about what a load is actually doing. For a hardware-level guarantee, the OFF position can additionally interrupt the SSR control line so that a firmware fault cannot override a lockout.

## 6 Firmware architecture

The firmware is a set of cooperating FreeRTOS tasks. Because the device is autonomous, the schedule lives in non-volatile storage (NVS) and runs with or without the network.

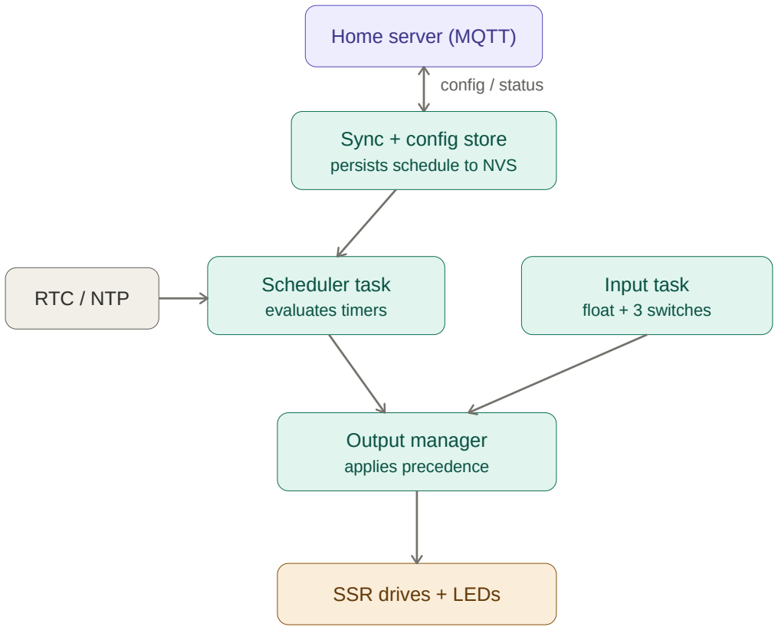
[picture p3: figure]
Home server (MQTT); config / status; Sync + config store; persists schedule to NVS; RTC / NTP; Scheduler task; evaluates timers; Input task; float + 3 switches; Output manager; applies precedence; SSR drives + LEDs

Figure 2 — FreeRTOS task and data flow inside the autonomous firmware.

Task | Responsibility
Sync + config store | Receives configuration over MQTT, validates it, and persists it to NVS. Notifies the scheduler to reload.
Scheduler | Wakes roughly once a minute, compares each output's on/off timer and active days against the RTC, and sets the desired AUTO state.
Input task | Debounces the float sensor and reads the three switch positions; raises events for the output manager.
Output manager | Resolves every output through the precedence rules below and drives the SSR control lines and indicator LEDs. Also owns the float-fill and leak logic.

Shared state (the live configuration and resolved output states) is guarded by a mutex; tasks communicate desired changes through queues or event groups so no task touches a GPIO that another task owns.

## 7 Output precedence logic

The output manager is where the physical switch, the schedule, the float logic, and leak protection all collide. Defining the priority order is the single most important correctness decision in the firmware. For each output, resolve from highest priority to lowest:

1. Leak lockout active → force OFF. Latched; clears only on an explicit reset, exactly like the original's leak guard.
2. Physical switch in OFF → force OFF. The hardware safety lockout.
3. Physical switch in ON → force ON. Manual override.
4. Physical switch in AUTO → defer to firmware. Pumps follow their schedule; the fill valve follows the float-fill logic plus its own schedule.

The indicator LED reflects the resolved state, never the raw command. A pump locked off by its switch shows OFF even if the schedule wants it on — the panel stays honest about what each load is actually

## 8 Configuration model

The device owns one JSON configuration blob stored in NVS — the JSON-native successor to PondPi's config.txt . The server publishes it; the device persists it. A monotonically increasing version counter lets the device tell whether an incoming message is newer than what it already holds. ESP-IDF's bundled

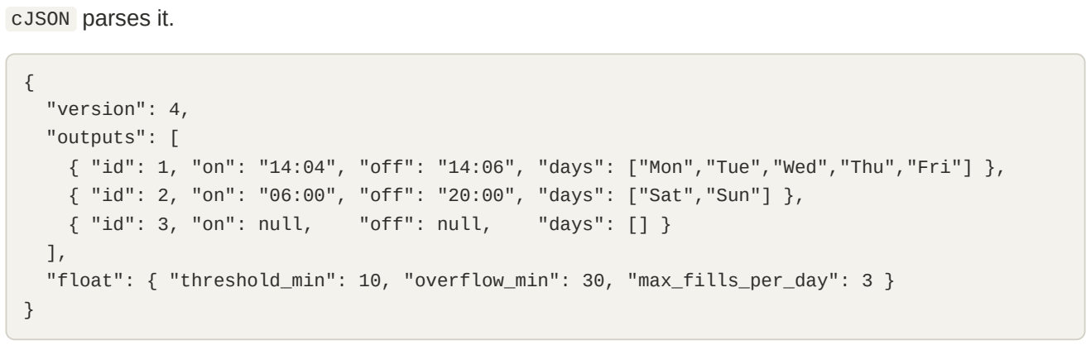
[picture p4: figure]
cJSON parses it.; "version": 4, "outputs": [; { "id": 3, "on": null,; "off": null,; "days": [] }

{ "id": 1, "on": "14:04", "off": "14:06", "days": ["Mon","Tue","Wed","Thu","Fri"] }, { "id": 2, "on": "06:00", "off": "20:00", "days": ["Sat","Sun"] },

"float": { "threshold_min": 10, "overflow_min": 30, "max_fills_per_day": 3 }

Times are stored in 24-hour form to avoid the AM/PM parsing fragility of the original. Output 3 (water fill) may carry a null schedule when it is driven purely by the float sensor.

## 9 Sync protocol & timekeeping

MQTT topics

MQTT with retained messages is a natural fit for an autonomous device: a freshly rebooted unit receives the latest schedule the instant it subscribes, with no live server interaction required. A Last-Will message gives the server a reliable online/offline signal.

Topic | Publisher | Notes
pond/config | server | Retained JSON blob; device writes to NVS when version increases.
pond/status | device | Retained; resolved output states and last-synced version.
pond/availability | device | MQTT Last-Will: online / offline .
pond/cmd | server | Optional momentary commands, e.g. clear leak lockout.

Timekeeping

On boot the device synchronizes time via SNTP and sets its timezone (for example EST5EDT ) so that local schedule comparisons are correct across daylight-saving changes. A DS3231 RTC with a coin-cell backup is optional insurance: it keeps accurate time through internet outages and across power loss, addressing the clock-drift gap in the original design.

## 10 ESP-IDF project structure

One component per concern keeps the build clean and maps directly onto the task diagram.

pond-control-unit/
├─ main/ | app_main: nvs + wifi + sntp init, task launch
├─ components/
│ ├─ config/ | NVS read/write, cJSON schema parse/validate
│ ├─ scheduler/ | per-minute timer evaluation, Timer model
│ ├─ input/ | GPIO debounce: float + 3-position switches
│ ├─ output_manager/ | precedence resolver, drives SSR + LED GPIO
│ ├─ timekeeping/ | SNTP + timezone, optional DS3231 over I2C
│ └─ net/ | wifi provisioning + esp-mqtt sync
└─ CMakeLists.txt

Phases 0–4 of the plan (Section 14) produce a fully working autonomous controller on the bench using only
the config , scheduler , input , output_manager , and timekeeping components — the network layer
is added last.

## 11 Home server

The home server's job is deliberately small: edit schedules and publish the resulting configuration. It is not in the real-time control path. A practical stack is an MQTT broker (Mosquitto) plus a lightweight web application (FastAPI or Node) that:

renders an admin panel for editing each output's on/off times and active days, and the float threshold/overflow/leak parameters;
writes a new retained pond/config message with an incremented version whenever the user saves; subscribes to pond/status and pond/availability to show live device state and online status.

Because the configuration is retained on the broker, the server itself can be down whenever it is not actively being used — the device already holds everything it needs.

## 12 PCB design

The board is designed as two electrically separated domains on one piece of FR4, because it mixes 3.3 V logic with switched 120 V. A logic (SELV) domain and a mains domain are split by an isolation barrier; the only things that cross it are the isolated AC-DC converter and the opto-triacs.

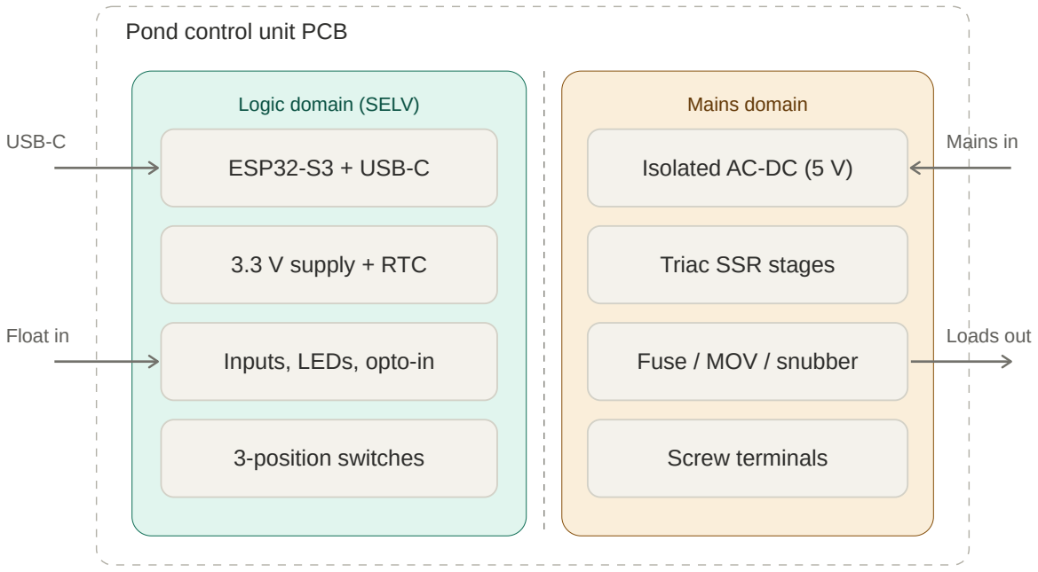
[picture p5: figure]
Pond control unit PCB; Logic domain (SELV); Mains domain; ESP32-S3 + USB-C; 3.3 V supply + RTC; Inputs, LEDs, opto-in; 3-position switches; Isolated AC-DC (5 V); Triac SSR stages; Fuse / MOV / snubber; Screw terminals; USB-C; Float in; Mains in; Loads out

Isolation barrier — creepage + clearance, slotted under optos

Figure 3 — PCB partitioned into a logic domain and a mains domain.

Power chain

Mains enters through an L/N/PE screw terminal behind a slow-blow fuse, with an MOV across line-to-neutral. It feeds an isolated AC-DC module sized with headroom — the ESP32-S3's WiFi current spikes to roughly half an amp, and the opto and indicator LEDs add to that, so a 5 W (1 A) module such as the HLK-5M05 is a safer pick than the 3 W parts that run right at their limit. From the isolated 5 V rail, a small buck converter steps down to 3.3 V (more efficient and cooler than an LDO), with bulk capacitance on both rails and tight decoupling at the module. With a protective-earth conductor present, the board is treated as earthed Class I and PE is bonded to the enclosure.

Per-channel triac SSR stage (×3)

Each of the three channels is identical. A GPIO drives the opto-triac's LED through a series resistor; the opto's output triac fires the gate of a power triac, which sits in series with the line feeding the load. The optocoupler is what makes a single-board design safe — the isolation barrier runs straight through it.

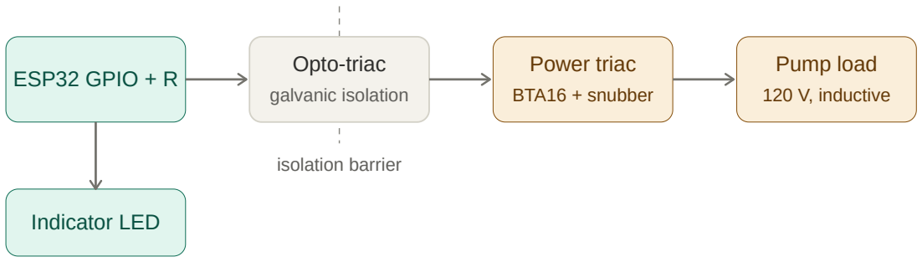
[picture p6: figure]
ESP32 GPIO + R; Opto-triac; galvanic isolation; Power triac; BTA16 + snubber; Pump load; 120 V, inductive; isolation barrier; Indicator LED

Figure 4 — One of three identical triac SSR channels.

A BTA-series triac is the right family because the "A" denotes an isolated tab, which makes heatsinking simple. Fountain pumps are typically under an amp, so a BTA16 leaves large margin and runs cool. One nuance from the inductive-load choice: zero-cross opto-triacs are tuned for resistive loads, so for motor loads either use a snubberless triac (the BTA "W" suffix) with an RC snubber, or a random-phase opto-triac, and size the snubber against the triac's commutating dv/dt rating. An RC snubber — on the order of 100 Ω in series with a 100 nF X-rated capacitor — across each triac is not optional with inductive loads. The indicator LED stays on the logic side, driven straight from the GPIO, so it shows the resolved state without touching mains.

Isolation & safety

No copper trace should bridge the two domains. The isolated AC-DC transformer and the opto-triacs provide the only galvanic crossings. Across that barrier the board needs reinforced-insulation spacing: a common rule of thumb for a 120 V line is on the order of 6–8 mm of creepage, helped by milling a slot through the board under the optos and the AC-DC module so surface tracking cannot shortcut it.

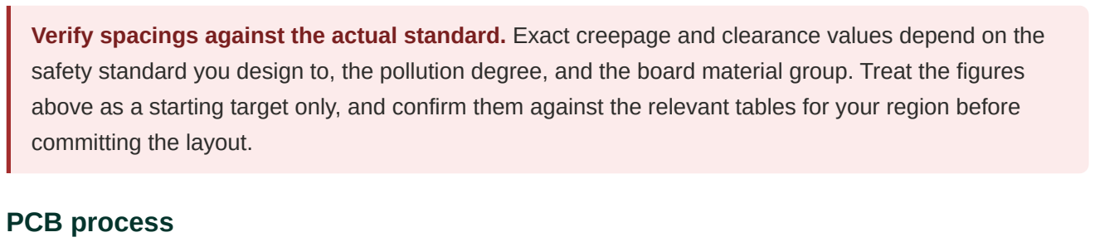
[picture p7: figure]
committing the layout.; PCB process

Verify spacings against the actual standard. Exact creepage and clearance values depend on the safety standard you design to, the pollution degree, and the board material group. Treat the figures above as a starting target only, and confirm them against the relevant tables for your region before

Tooling: KiCad for schematic capture and layout. Pull libraries for the WROOM module, the AC-DC module, the opto/triac parts, the DS3231, and rated terminal blocks.
Layers: a 2-layer board is feasible with care, but 4 layers make the power/ground planes and RF routing much easier and are worthwhile for a board carrying mains.
Layout: partition the domains, route the isolation slot, widen the mains traces for pump current (2 oz copper or wide pours), and keep copper out from under the module's antenna at the board edge. Add test points on every rail.

Fabrication: JLCPCB or PCBWay, with optional assembly of the SMT parts. Bring rev A up in stages — populate and verify the isolated 5 V and 3.3 V rails before the ESP32 is ever populated.

## 13 Indicative bill of materials

Candidate parts by functional block. Values and exact part numbers should be confirmed against datasheets and the final load ratings.

Block | Candidate part | Notes
MCU module | ESP32-S3-WROOM-1 (N8 / N8R8) | Native USB; antenna keep-out at board edge.
USB | USB-C receptacle + USBLC6-2 ESD | Wired to the S3 native USB for flash/JTAG.
AC-DC | HLK-5M05 (5 V / 5 W isolated) | Headroom over WiFi current peaks.
3.3 V regulator | Buck (e.g. TPS562201 / MP1584) | LDO (AMS1117-3.3) acceptable but warmer.
RTC | DS3231SN + CR2032 holder | Battery-backed time over I2C.
Opto-triac driver ×3 | MOC3052 (random-phase) or MOC3062 (zero-cross) | Choice depends on load and snubber design.
Power triac ×3 | BTA16-600BW (snubberless, isolated tab) | Large margin over typical pump current.
Snubber ×3 | ≈100 Ω 0.5 W + 100 nF X2 cap | Required for inductive motor loads.
Input protection | Fuse + holder, MOV rated for the 120 V line | Slow-blow fuse sized for board + inrush.
Float input | TVS (e.g. SMAJ5.0A) + series resistor + RC | Protects the long outdoor sensor run.
Indicators | 4 × LED + current-limit resistors | Three outputs plus float, on the logic side.
Switches ×3 | SPDT center-off (ON/OFF/AUTO) | Panel- or board-mounted to the faceplate.
Terminals | Mains-rated screw terminals (300 V) | L/N/PE in, three load outputs, float in.

## 14 Plan of attack

Firmware is validated on a dev board first; the PCB is designed only once the circuit is proven on prototype hardware. Phases 0–4 yield a working autonomous controller on the bench with no server and no custom board.

Phase | Work
0 — Toolchain | Install ESP-IDF, idf.py set-target esp32s3 , flash the blink example to confirm the board and USB-JTAG.
1 — Bare I/O | Drive one LED; read a 3-position switch and the float sensor with software debounce; log states. No logic yet.
2 — Timekeeping | SNTP sync, set timezone, confirm local time across a reboot; add the DS3231 if offline accuracy is wanted.
3 — Scheduler + output manager | Port the timer model, load config from NVS (hardcoded blob first), implement the precedence resolver; run fully offline.
4 — Float-fill + leak | Port the float-fill threshold/overflow logic and the daily fill-count leak guard.
5 — Connectivity | WiFi + esp-mqtt; subscribe to retained pond/config , persist on version bump, publish status and Last-Will.
6 — Prototype circuit | Build the complete circuit on protoboard — every input, real switches and LEDs, real SSR modules — and freeze the schematic.
7 — Schematic capture | Enter the schematic in KiCad and run ERC.
8 — PCB layout | Partition the domains, route the isolation slot, set creepage/clearance, widen mains traces, honor the antenna keep-out; run DRC.
9 — Fab + bring-up | Fabricate and assemble rev A; bring up power rails first, then the rest.
10 — Hardware firmware | Bring-up firmware; spin rev B for fixes and to fold in the on-board AC-DC if deferred.
11 — Home server | Mosquitto plus the admin panel that edits and publishes the retained config.
12 — Enclosure | IP-rated box, sealed switch/LED faceplate, GFCI on the pond circuit, conformal coating, soak test.

## 15 Safety notice

This project switches mains voltage near water. Both are independently capable of causing serious injury or death, and the combination demands real caution.

Have the mains section of the design reviewed by someone qualified in mains PCB work before fabrication.
Bring rev A up through an isolation transformer and, ideally, a current-limited supply; never make contact with the board while it is powered from mains.
Confirm all creepage and clearance distances against the safety standard applicable in your region. Install the unit behind a GFCI / RCD, bond protective earth to the enclosure, and use an IP-rated, conformally-coated assembly for outdoor use.
Follow your local electrical code; in many jurisdictions permanent mains wiring must be performed or inspected by a licensed electrician.

This document is a design plan, not a certified or inspected design. You are responsible for the safety of anything you build from it.

## 16 Appendix

Pin budget

Category | Count | Lines
Inputs | 4 | Float sensor + three switch positions (or 6 lines if each 3-position switch uses two GPIO).
SSR drives | 3 | Opto-triac LED per channel.
Indicator LEDs | 4 | Three outputs plus float.
I2C (RTC) | 2 | SDA / SCL to the DS3231.

Roughly 13–16 GPIO including the RTC bus — comfortably within the ESP32-S3's available pins.

References

Original project: PondPi by Noah Robertson — github.com/nhrobertson/PondPi (MIT License). ESP-IDF programming guide and component reference (Espressif).
Opto-triac driver application notes (e.g. ON Semiconductor MOC30xx series) for inductive-load snubber design.

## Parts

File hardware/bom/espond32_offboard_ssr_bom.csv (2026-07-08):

Section | Designator | Qty | Description | Value | Manufacturer | MPN | Distributor | Distributor_PN | Purchase_URL | KiCad_Symbol | KiCad_Footprint | Datasheet_URL | Notes
MCU | U1 | 1 | ESP32-S3 WiFi/BT module - NO PSRAM variant | ESP32-S3-WROOM-1-N8 | Espressif Systems | ESP32-S3-WROOM-1-N8 | DigiKey | 15200089 | https://www.digikey.com/en/products/detail/espressif-systems/ESP32-S3-WROOM-1-N8/15200089 | RF_Module:ESP32-S3-WROOM-1 | RF_Module:ESP32-S3-WROOM-1 | https://www.espressif.com/sites/default/files/documentation/esp32-s3-wroom-1_wroom-1u_datasheet_en.pdf | MUST be the N8 (quad flash, no PSRAM) variant. config.h uses GPIO35/36/37/38 as DEBUG_GPIO test points - the R8/R16/N8R8/N16R8 variants use GPIO33-37 internally for octal PSRAM, which would conflict. Symbol/footprint from Espressif's official KiCad library (github.com/espressif/kicad-libraries, install via KiCad Plugin & Content Manager).
MCU | J1 | 1 | USB-C receptacle - native USB for flash/JTAG/console + bench power | USB4105-GF-A | GCT | USB4105-GF-A | DigiKey | 11198441 | https://www.digikey.com/en/products/detail/gct/USB4105-GF-A/11198441 | Connector_USB:USB_C_Receptacle_USB2.0 | Connector_USB:USB_C_Receptacle_GCT_USB4105-xx-A_16P_TopMnt_Horizontal | https://gct.co/connector/usb4105 | D+/D- to ESP32-S3 GPIO20/GPIO19 (fixed native-USB pins). This board carries no mains, so USB-C VBUS can double as a bench power input; field power comes from J-PWR instead (see Power section) since USB-C is a poor fit for a sealed outdoor enclosure.
MCU | R-CC1;R-CC2 | 2 | USB-C CC1/CC2 identification resistors | 5.1k 1% 0805 | generic | - | DigiKey/Mouser | - | https://www.digikey.com/en/products/filter/chip-resistor-surface-mount/52 | Device:R | Resistor_SMD:R_0805_2012Metric | - | Required for UFP (device) detection on USB-C. Standard value, any 1% 0805 resistor.
MCU | D1 | 1 | USB D+/D- ESD protection array | USBLC6-2SC6 | STMicroelectronics | USBLC6-2SC6 | DigiKey | 1040559 | https://www.digikey.com/en/products/detail/stmicroelectronics/USBLC6-2SC6/1040559 | Power_Protection:USBLC6-2SC6 | Package_TO_SOT_SMD:SOT-23-6 | https://www.st.com/resource/en/datasheet/usblc6-2.pdf | Place close to J1 on the D+/D- lines before they reach the module.
MCU | R-EN | 1 | EN pull-up | 10k 0603 | generic | - | DigiKey/Mouser | - | - | Device:R | Resistor_SMD:R_0603_1608Metric | - | Ties EN high per Espressif reference design; module resets while EN is low.
MCU | C-EN | 1 | EN power-on delay cap | 1uF 0603 | generic | - | DigiKey/Mouser | - | - | Device:C | Capacitor_SMD:C_0603_1608Metric | - | Optional but recommended for a clean power-on reset edge.
MCU | SW6 | 1 | BOOT/download-mode tactile button | 6x6mm THT tactile | generic | - | DigiKey | - | https://www.digikey.com/en/products/filter/tactile-switches/197 | Switch:SW_Push | Button_Switch_THT:SW_PUSH_6mm | - | Pulls GPIO0 (strapping pin) to GND when held - needed to force download mode if esptool's automatic USB-JTAG reset ever fails in the field.
MCU | R-BOOT | 1 | GPIO0 pull-up | 10k 0603 | generic | - | DigiKey/Mouser | - | - | Device:R | Resistor_SMD:R_0603_1608Metric | - | Keeps GPIO0 high (normal boot) when SW6 is not pressed.
MCU | C-DECAP1;C-DECAP2 | 2 | Module VDD bulk decoupling | 10uF 0805 | generic | - | DigiKey/Mouser | - | - | Device:C | Capacitor_SMD:C_0805_2012Metric | - | One per VDD pin group per Espressif hardware design guidelines; place close to module pins.
MCU | C-DECAP3;C-DECAP4 | 2 | Module VDD local decoupling | 0.1uF 0402 | generic | - | DigiKey/Mouser | - | - | Device:C | Capacitor_SMD:C_0402_1005Metric | - | Tight decoupling directly at module VDD pins.
Power | J-PWR | 1 | Field 5V DC power input | 2-position 5.08mm | Phoenix Contact | 1715721 | DigiKey | 260631 | https://www.digikey.com/en/products/detail/phoenix-contact/1715721/260631 | Connector_Generic:Conn_01x02 | TerminalBlock_Phoenix.pretty:TerminalBlock_Phoenix_MKDS-1,5-2-5.08_1x02_P5.08mm_Horizontal | - | Board is entirely SELV/low-voltage - powered from an external 5V wall-wart/supply feeding this terminal block, not from mains directly. No isolated AC-DC, fuse, or MOV needed on this board at all.
Power | D-OR1;D-OR2 | 2 | Power-input OR-ing Schottky diodes (USB-C VBUS vs. J-PWR) | SS14 | onsemi | SS14 | DigiKey | 965474 | https://www.digikey.com/en/products/detail/onsemi/SS14/965474 | Device:D_Schottky | Diode_SMD:D_SMA | https://www.onsemi.com/products/discrete-power-modules/schottky-diodes-schottky-rectifiers/ss14 | One in series with USB-C VBUS, one in series with J-PWR, diode-ORed onto the shared 5V rail so plugging in USB for bench flashing never backfeeds the field supply (or vice versa).
Power | U3 | 1 | 3.3V synchronous buck regulator | TPS563201DDCR | Texas Instruments | TPS563201DDCR | DigiKey | 5808204 | https://www.digikey.com/en/products/detail/texas-instruments/TPS563201DDCR/5808204 | Regulator_Switching:TPS563201DDCR | Package_TO_SOT_SMD:SOT-23-6 | https://www.ti.com/lit/ds/symlink/tps563201.pdf | Steps the 5V rail down to 3.3V for the module + control outputs + LED chain. Use TI's datasheet application circuit for L1/C1-C4 sizing.
Power | L1 | 1 | Buck output inductor | 2.2uH shielded power inductor | Wurth Elektronik | 74437324022 | DigiKey/Mouser | - | https://www.digikey.com/en/products/detail/wurth-electronics-inc/744373240/5352546 | Device:L | Inductor_SMD:L_Wuerth_WE-PD3-1040 | https://www.we-online.com | Value per TI TPS563201 datasheet application circuit; substitute any equivalent shielded 2.2uH/>2A inductor.
Power | C1;C2 | 2 | Buck input/output ceramic caps | 10uF 25V X7R 0805 | generic | - | DigiKey/Mouser | - | - | Device:C | Capacitor_SMD:C_0805_2012Metric | - | Per TPS563201 datasheet application circuit.
Power | C3 | 1 | 5V rail bulk capacitance | 22uF 16V electrolytic or ceramic | generic | - | DigiKey/Mouser | - | - | Device:C | CP_Radial_D5.0mm_P2.50mm | - | Bulk cap on the 5V rail feeding U3 and the LED chain.
Power | C4 | 1 | 3.3V rail bulk capacitance (post buck) | 22uF 10V ceramic | generic | - | DigiKey/Mouser | - | - | Device:C | Capacitor_SMD:C_1210_3225Metric | - | Bulk cap on the 3.3V logic rail.
Control output x4 (Pump1/Pump2/Valve1/Light1) | Q1;Q2;Q3;Q4 | 4 | Logic-level N-channel MOSFET - low-side driver for external SSR/relay module control input | 2N7000 | onsemi | 2N7000 | DigiKey | 244278 | https://www.digikey.com/en/products/detail/onsemi/2N7000/244278 | Transistor_FET:2N7000 | Package_TO_SOT_THT:TO-92_Inline | https://www.onsemi.com/pdf/datasheet/2n7000-d.pdf | Replaces the on-board triac stage entirely - no mains-side parts on this board. GPIO drives the gate; drain sinks the external SSR/relay module's control '-' terminal to GND when on, source to GND. Buffering through a MOSFET (rather than driving the module's opto input straight off a 3.3V GPIO) gives a full 5V logic swing, which is safely within spec for the widest range of off-the-shelf 3-32VDC SSR/relay modules - some are marginal at bare 3.3V.
Control output x4 | R1;R2;R3;R4 | 4 | MOSFET gate series resistor | 220 ohm 1/8W 0603 | generic | - | DigiKey/Mouser | - | - | Device:R | Resistor_SMD:R_0603_1608Metric | - | Between the ESP32 SSR GPIO and each 2N7000 gate.
Control output x4 | R5;R6;R7;R8 | 4 | MOSFET gate pulldown | 100k 1/8W 0603 | generic | - | DigiKey/Mouser | - | - | Device:R | Resistor_SMD:R_0603_1608Metric | - | Holds each gate low (output off) while the GPIO is undriven/tri-stated during boot.
Control output x4 | J3;J4;J5;J6 | 4 | External SSR/relay module control-output terminal block (per channel) | 2-position 5.08mm | Phoenix Contact | 1715721 | DigiKey | 260631 | https://www.digikey.com/en/products/detail/phoenix-contact/1715721/260631 | Connector_Generic:Conn_01x02 | TerminalBlock_Phoenix.pretty:TerminalBlock_Phoenix_MKDS-1,5-2-5.08_1x02_P5.08mm_Horizontal | https://www.phoenixcontact.com/en-us/products/printed-circuit-board-terminal-mkds-15-2-508-1715721 | Carries only the 5V control-side signal to an external SSR/relay module (control '+' wired to the module directly from the 5V rail off-board, control '-' from this terminal through the MOSFET drain). No mains anywhere on this board.
Control output (not stocked here - purchase separately per channel) | SSR1;SSR2;SSR3;SSR4 | 4 | Off-board panel/DIN-rail-mount solid-state relay module | SSR-25DA (3-32VDC in / 24-480VAC out) or equivalent | Fotek (or equivalent) | SSR-25DA | varies | - | https://www.fotek.com.tw/en-gb/product-category/143 | N/A - external module | N/A - external module | - | Reference part only, not part of this board's BOM. Mains L/N wiring runs directly from the incoming supply through each module's load terminals to the pump/valve/light, physically bypassing this PCB entirely - see the on-board-SSR variant if you want everything on one board instead. Verify the chosen module's input trigger current/voltage and its own mains-side fusing/MOV needs, which live in the external wiring harness, not on this board.
Float input | J7 | 1 | Float sensor input terminal block | 2-position 5.08mm | Phoenix Contact | 1715721 | DigiKey | 260631 | https://www.digikey.com/en/products/detail/phoenix-contact/1715721/260631 | Connector_Generic:Conn_01x02 | TerminalBlock_Phoenix.pretty:TerminalBlock_Phoenix_MKDS-1,5-2-5.08_1x02_P5.08mm_Horizontal | - | Low-voltage (3.3V-side) signal.
Float input | D2 | 1 | Float sensor line TVS protection | SMAJ5.0A | Littelfuse | SMAJ5.0A | DigiKey | 762250 | https://www.digikey.com/en/products/detail/littelfuse-inc/SMAJ5-0A/762250 | Diode:SMAJ5.0A | Diode_SMD:D_SMA | https://www.littelfuse.com/media?resourcetype=datasheets&itemid=e677f19f-799f-45ff-a967-bc36ad9640b3 | Protects FLOAT1_SENS_GPIO for the long outdoor sensor run called out in the doc.
Float input | R13 | 1 | Float sensor series resistor | 1k 0603 | generic | - | DigiKey/Mouser | - | - | Device:R | Resistor_SMD:R_0603_1608Metric | - | Between J7 and the GPIO/TVS node.
Float input | C9 | 1 | Float sensor RC filter cap | 4.7nF 0603 | generic | - | DigiKey/Mouser | - | - | Device:C | Capacitor_SMD:C_0603_1608Metric | - | Forms an RC low-pass with R13 against noise pickup on the long outdoor run.
Indicators | D3;D4;D5;D6;D7;D8 | 6 | Individually-addressable RGB LED | WS2812B (5050 SMD) | XINGLIGHT | XL-5050RGBC-WS2812B | DigiKey | 25673106 | https://www.digikey.com/en/products/detail/xinglight/XL-5050RGBC-WS2812B/25673106 | LED:WS2812B | LED_SMD:LED_WS2812B_PLCC4_5.0x5.0mm_P3.2mm | https://cdn-shop.adafruit.com/datasheets/WS2812B.pdf | Firmware drives one WS2812 chain of 6 pixels (Pump1, Pump2, Valve1, Light1, Float, Sys) off GPIO10 via the led_strip RMT driver - NOT 4 discrete LED+resistor pairs as in the design doc's indicative BOM. Chain DIN->DOUT in firmware pixel order 0-5 (config.h *_LED_PIX defines).
Indicators | C10;C11;C12;C13;C14;C15 | 6 | Per-LED decoupling cap | 100nF 0402 | generic | - | DigiKey/Mouser | - | - | Device:C | Capacitor_SMD:C_0402_1005Metric | - | One per WS2812B per datasheet recommendation.
Indicators | R14 | 1 | LED data line series resistor | 330 ohm 0603 | generic | - | DigiKey/Mouser | - | - | Device:R | Resistor_SMD:R_0603_1608Metric | - | Between GPIO10 (LED_DATA_GPIO) and the first WS2812B DIN - standard practice to limit ringing/inrush on the data line.
Switches | SW1;SW2;SW3;SW4 | 4 | 3-position center-off switch (ON/AUTO/OFF) | SPDT ON-NONE-ON PC-pin | E-Switch | 100SP1T1B1M2QEH | DigiKey | - | https://www.digikey.com/en/products/detail/e-switch/100SP1T1B1M2QEH/ | Switch:SW_SPDT | Custom - THT PC-pin, panel bushing through enclosure faceplate (no standard KiCad footprint; build a 3-pad THT footprint per datasheet) | https://www.e-switch.com/product/100-series-miniature-toggle-switch/ | One per output channel (Pump1, Pump2, Valve1, Light1). Common -> 3V3, throw A -> SW_A GPIO, throw B -> SW_B GPIO. Firmware already configures SW_A/SW_B as GPIO_PULLDOWN_ONLY inputs, so no external pull resistors are needed - center/AUTO position reads both low.
Switches | SW5 | 1 | Reset / leak-lockout-clear pushbutton | Panel-actuated tactile | E-Switch | TL1220S1BBSG-RESET | DigiKey | 4029332 | https://www.digikey.com/en/products/detail/e-switch/TL1220S1BBSG-RESET/4029332 | Switch:SW_Push | Button_Switch_THT:SW_TL1220 | https://www.e-switch.com | Wired to RESET_BTN_GPIO, idle-high via internal pull-up (GPIO_PULLUP_ONLY in firmware, no external resistor needed). Firmware requires a 5s hold to clear the leak lockout and esp_restart().
Debug (optional - populate for bring-up only) | J8 | 1 | Debug/test-point header | 1x10 2.54mm pin header | generic | - | DigiKey/Mouser | - | - | Connector_Generic:Conn_01x10 | Connector_PinHeader_2.54mm:PinHeader_1x10_P2.54mm_Vertical | - | Breaks out the 9 DEBUG_GPIO_* task-timing test points (config.h) + GND for a logic analyzer during bring-up. Omit for a production board, or gate behind DEBUG_GPIO_ENABLE.

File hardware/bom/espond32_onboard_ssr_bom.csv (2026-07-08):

Section | Designator | Qty | Description | Value | Manufacturer | MPN | Distributor | Distributor_PN | Purchase_URL | KiCad_Symbol | KiCad_Footprint | Datasheet_URL | Notes
MCU | U1 | 1 | ESP32-S3 WiFi/BT module - NO PSRAM variant | ESP32-S3-WROOM-1-N8 | Espressif Systems | ESP32-S3-WROOM-1-N8 | DigiKey | 15200089 | https://www.digikey.com/en/products/detail/espressif-systems/ESP32-S3-WROOM-1-N8/15200089 | RF_Module:ESP32-S3-WROOM-1 | RF_Module:ESP32-S3-WROOM-1 | https://www.espressif.com/sites/default/files/documentation/esp32-s3-wroom-1_wroom-1u_datasheet_en.pdf | MUST be the N8 (quad flash, no PSRAM) variant. config.h uses GPIO35/36/37/38 as DEBUG_GPIO test points - the R8/R16/N8R8/N16R8 variants use GPIO33-37 internally for octal PSRAM, which would conflict. Symbol/footprint from Espressif's official KiCad library (github.com/espressif/kicad-libraries, install via KiCad Plugin & Content Manager).
MCU | J1 | 1 | USB-C receptacle - native USB for flash/JTAG/console | USB4105-GF-A | GCT | USB4105-GF-A | DigiKey | 11198441 | https://www.digikey.com/en/products/detail/gct/USB4105-GF-A/11198441 | Connector_USB:USB_C_Receptacle_USB2.0 | Connector_USB:USB_C_Receptacle_GCT_USB4105-xx-A_16P_TopMnt_Horizontal | https://gct.co/connector/usb4105 | D+/D- to ESP32-S3 GPIO20/GPIO19 (fixed native-USB pins - do not reuse elsewhere, config.h does not use them). CC1/CC2 need 5.1k to GND (see R-CC below) for the port to present as a USB device.
MCU | R-CC1;R-CC2 | 2 | USB-C CC1/CC2 identification resistors | 5.1k 1% 0805 | generic | - | DigiKey/Mouser | - | https://www.digikey.com/en/products/filter/chip-resistor-surface-mount/52 | Device:R | Resistor_SMD:R_0805_2012Metric | - | Required for UFP (device) detection on USB-C. Standard value, any 1% 0805 resistor.
MCU | D1 | 1 | USB D+/D- ESD protection array | USBLC6-2SC6 | STMicroelectronics | USBLC6-2SC6 | DigiKey | 1040559 | https://www.digikey.com/en/products/detail/stmicroelectronics/USBLC6-2SC6/1040559 | Power_Protection:USBLC6-2SC6 | Package_TO_SOT_SMD:SOT-23-6 | https://www.st.com/resource/en/datasheet/usblc6-2.pdf | Place close to J1 on the D+/D- lines before they reach the module.
MCU | R-EN | 1 | EN pull-up | 10k 0603 | generic | - | DigiKey/Mouser | - | - | Device:R | Resistor_SMD:R_0603_1608Metric | - | Ties EN high per Espressif reference design; module resets while EN is low.
MCU | C-EN | 1 | EN power-on delay cap | 1uF 0603 | generic | - | DigiKey/Mouser | - | - | Device:C | Capacitor_SMD:C_0603_1608Metric | - | Optional but recommended for a clean power-on reset edge.
MCU | SW6 | 1 | BOOT/download-mode tactile button | 6x6mm THT tactile | generic | - | DigiKey | - | https://www.digikey.com/en/products/filter/tactile-switches/197 | Switch:SW_Push | Button_Switch_THT:SW_PUSH_6mm | - | Pulls GPIO0 (strapping pin) to GND when held - needed to force download mode if esptool's automatic USB-JTAG reset ever fails in the field.
MCU | R-BOOT | 1 | GPIO0 pull-up | 10k 0603 | generic | - | DigiKey/Mouser | - | - | Device:R | Resistor_SMD:R_0603_1608Metric | - | Keeps GPIO0 high (normal boot) when SW6 is not pressed.
MCU | C-DECAP1;C-DECAP2 | 2 | Module VDD bulk decoupling | 10uF 0805 | generic | - | DigiKey/Mouser | - | - | Device:C | Capacitor_SMD:C_0805_2012Metric | - | One per VDD pin group per Espressif hardware design guidelines; place close to module pins.
MCU | C-DECAP3;C-DECAP4 | 2 | Module VDD local decoupling | 0.1uF 0402 | generic | - | DigiKey/Mouser | - | - | Device:C | Capacitor_SMD:C_0402_1005Metric | - | Tight decoupling directly at module VDD pins.
Power | U2 | 1 | Isolated AC-DC 220V->5V 5W | HLK-5M05 | Hi-Link | HLK-5M05 | LCSC | C209907 | https://www.lcsc.com/product-detail/C209907.html | Isolator:HLK-5M05 (custom - create from datasheet) | Custom - 4-pin THT potted module (verify pin pitch against physical part before layout) | https://datasheet4u.com/datasheets/Hi-Link/HLK-5M05/1524017 | Not routinely stocked at DigiKey/Mouser - buy via LCSC or an Amazon/AliExpress listing for prototyping. 5W/1A gives headroom over the WROOM-1's ~0.5A WiFi TX current spikes plus opto+LED load, vs. 3W parts that run at their limit.
Power | F1 | 1 | Mains input fuse - slow-blow | 1A 250V 5x20mm | Littelfuse | 0218001.MXP | DigiKey | - | https://www.digikey.com/catalog/en/partgroup/218-series/28815 | Device:Fuse | Fuseholder_Cartridge:Fuseholder_Cartridge_5x20mm (paired with FH1) | https://www.littelfuse.com/assetdocs/fuse-218-datasheet | Slow-blow (Slo-Blo) 218 series, not the fast-acting 217 series. Confirm 1A is right once the final load + AC-DC inrush current is known at bring-up.
Power | FH1 | 1 | PCB-mount fuse holder for F1 | 5x20mm THT clip pair | Keystone Electronics | 4525 | DigiKey | - | https://www.digikey.com/catalog/en/partgroup/5mm-fuse-holders/33957 | Device:Fuseholder_Clip | Fuseholder_Cartridge:Fuseholder_Cartridge_Keystone_4525_5x20mm | - | PCB-mount clip-style holder rated 250V.
Power | RV1 | 1 | MOV - line-to-neutral surge suppression | 130VAC / 14mm disc | Littelfuse | V130LA10AP | DigiKey | 1009202 | https://www.digikey.com/en/products/detail/littelfuse-inc/V130LA10AP/1009202 | Device:Varistor | Varistor_THT:RV_Disc_D14mm_W7.5mm_P10mm (verify lead pitch against part) | https://m.littelfuse.com/media?filename=littelfuse-varistor-la-datasheet | Placed across L-N ahead of U2, behind F1.
Power | U3 | 1 | 3.3V synchronous buck regulator | TPS563201DDCR | Texas Instruments | TPS563201DDCR | DigiKey | 5808204 | https://www.digikey.com/en/products/detail/texas-instruments/TPS563201DDCR/5808204 | Regulator_Switching:TPS563201DDCR | Package_TO_SOT_SMD:SOT-23-6 | https://www.ti.com/lit/ds/symlink/tps563201.pdf | Steps isolated 5V rail down to 3.3V; more efficient/cooler than an LDO for the module + SSR + LED load. Use TI's datasheet application circuit for L1/C1-C4 sizing.
Power | L1 | 1 | Buck output inductor | 2.2uH shielded power inductor | Wurth Elektronik | 74437324022 | DigiKey/Mouser | - | https://www.digikey.com/en/products/detail/wurth-electronics-inc/744373240/5352546 | Device:L | Inductor_SMD:L_Wuerth_WE-PD3-1040 | https://www.we-online.com | Value per TI TPS563201 datasheet application circuit; substitute any equivalent shielded 2.2uH/>2A inductor.
Power | C1;C2 | 2 | Buck input/output ceramic caps | 10uF 25V X7R 0805 | generic | - | DigiKey/Mouser | - | - | Device:C | Capacitor_SMD:C_0805_2012Metric | - | Per TPS563201 datasheet application circuit.
Power | C3 | 1 | 5V rail bulk capacitance (post AC-DC) | 22uF 16V electrolytic or ceramic | generic | - | DigiKey/Mouser | - | - | Device:C | CP_Radial_D5.0mm_P2.50mm | - | Bulk cap on the isolated 5V rail feeding U3 and the LED chain.
Power | C4 | 1 | 3.3V rail bulk capacitance (post buck) | 22uF 10V ceramic | generic | - | DigiKey/Mouser | - | - | Device:C | Capacitor_SMD:C_1210_3225Metric | - | Bulk cap on the 3.3V logic rail.
SSR channel x4 (Pump1/Pump2/Valve1/Light1) | U5;U6;U7;U8 | 4 | Zero-cross optotriac driver | MOC3063 | onsemi / Lite-On | MOC3063 | DigiKey | 670014 | https://www.digikey.com/en/products/detail/liteon/MOC3063/670014 | Isolator:MOC3063 | Package_DIP:DIP-6_W7.62mm | https://www.onsemi.com/pdf/datasheet/moc3061m-d.pdf | One per output channel. Firmware has 4 output devices (2 pumps + valve + light), not the 3 in the design doc - size this section x4 throughout. Zero-cross type paired with a snubberless (W-suffix) triac per the doc's inductive-load guidance.
SSR channel x4 | Q1;Q2;Q3;Q4 | 4 | Snubberless isolated-tab power triac | BTA16-600BWRG | STMicroelectronics | BTA16-600BWRG | DigiKey | 654430 | https://www.digikey.com/en/products/detail/stmicroelectronics/BTA16-600BWRG/654430 | Triac:BTA16-600B | Package_TO_SOT_THT:TO-220-3_Vertical | https://www.st.com/resource/en/datasheet/bta16-600b.pdf | BTA16-600BW (the doc's original pick) is obsolete; BTA16-600BWRG is the current in-production part, same TO-220AB isolated-tab package/pinout. 16A rating leaves large margin over sub-1A fountain pump loads.
SSR channel x4 | R1;R2;R3;R4 | 4 | Optotriac LED series (drive) resistor | 180 ohm 1/8W 0603 | generic | - | DigiKey/Mouser | - | - | Device:R | Resistor_SMD:R_0603_1608Metric | - | From ESP32 SSR GPIO through MOC3063 pin1 (anode) to pin2 (cathode)/GND. Verify against the guaranteed IFT of the exact MOC3063 grade purchased - 180-220 ohm is typical for a 3.3V logic drive.
SSR channel x4 | R5;R6;R7;R8 | 4 | Optotriac-to-triac gate resistor | 100 ohm 1/4W THT | generic | - | DigiKey/Mouser | - | - | Device:R | Resistor_THT:R_Axial_DIN0207_L6.3mm_D2.5mm_P10.16mm_Horizontal | - | MOC3063 pin6 to triac gate. Optional per MOC30xx app note (some designs wire pin6 straight to gate) but recommended for gate current/surge limiting.
SSR channel x4 | R9;R10;R11;R12 | 4 | RC snubber resistor (across triac MT1-MT2) | 100 ohm 0.5W THT | generic | - | DigiKey/Mouser | - | - | Device:R | Resistor_THT:R_Axial_DIN0207_L9.9mm_D3.2mm_P15.24mm_Horizontal | - | Required with the snubberless BTA16-600BW's inductive pump/valve loads per the doc - not optional.
SSR channel x4 | C5;C6;C7;C8 | 4 | RC snubber capacitor (across triac MT1-MT2) | 100nF 275VAC X2 | KEMET | R46KI31000001M | DigiKey/Mouser | - | https://www.digikey.com/en/products/detail/kemet/R46KI31000001M/2617967 | Device:C | Capacitor_THT:C_Rect_L18.0mm_W10.0mm_P15.00mm | https://content.kemet.com/datasheets/KEM_F3110_R46.pdf | X2 safety-rated film cap in series with the snubber resistor, across each triac.
Mains I/O | J2 | 1 | Mains input terminal block - L/N/PE | 3-position 5.08mm 300V+ | Phoenix Contact | 1715734 | DigiKey/Mouser | - | https://www.digikey.com/en/products/detail/phoenix-contact/1715734/1004396 | Connector_Generic:Conn_01x03 | TerminalBlock_Phoenix.pretty:TerminalBlock_Phoenix_MKDS-1,5-3-5.08_1x03_P5.08mm_Horizontal | https://www.phoenixcontact.com | MKDS 1,5 series - 300-400V/17.5A rated screw terminal, UL/CSA approved.
Mains I/O | J3;J4;J5;J6 | 4 | Load output terminal block (per channel) | 2-position 5.08mm 300V+ | Phoenix Contact | 1715721 | DigiKey | 260631 | https://www.digikey.com/en/products/detail/phoenix-contact/1715721/260631 | Connector_Generic:Conn_01x02 | TerminalBlock_Phoenix.pretty:TerminalBlock_Phoenix_MKDS-1,5-2-5.08_1x02_P5.08mm_Horizontal | https://www.phoenixcontact.com/en-us/products/printed-circuit-board-terminal-mkds-15-2-508-1715721 | One per SSR channel output (Pump1, Pump2, Valve1, Light1) - x4, not the doc's x3.
Float input | J7 | 1 | Float sensor input terminal block | 2-position 5.08mm | Phoenix Contact | 1715721 | DigiKey | 260631 | https://www.digikey.com/en/products/detail/phoenix-contact/1715721/260631 | Connector_Generic:Conn_01x02 | TerminalBlock_Phoenix.pretty:TerminalBlock_Phoenix_MKDS-1,5-2-5.08_1x02_P5.08mm_Horizontal | - | Low-voltage (3.3V-side) signal - same connector family reused for parts consistency; a smaller-pitch part is fine too.
Float input | D2 | 1 | Float sensor line TVS protection | SMAJ5.0A | Littelfuse | SMAJ5.0A | DigiKey | 762250 | https://www.digikey.com/en/products/detail/littelfuse-inc/SMAJ5-0A/762250 | Diode:SMAJ5.0A | Diode_SMD:D_SMA | https://www.littelfuse.com/media?resourcetype=datasheets&itemid=e677f19f-799f-45ff-a967-bc36ad9640b3 | Protects FLOAT1_SENS_GPIO for the long outdoor sensor run called out in the doc.
Float input | R13 | 1 | Float sensor series resistor | 1k 0603 | generic | - | DigiKey/Mouser | - | - | Device:R | Resistor_SMD:R_0603_1608Metric | - | Between J7 and the GPIO/TVS node.
Float input | C9 | 1 | Float sensor RC filter cap | 4.7nF 0603 | generic | - | DigiKey/Mouser | - | - | Device:C | Capacitor_SMD:C_0603_1608Metric | - | Forms an RC low-pass with R13 against noise pickup on the long outdoor run.
Indicators | D3;D4;D5;D6;D7;D8 | 6 | Individually-addressable RGB LED | WS2812B (5050 SMD) | XINGLIGHT | XL-5050RGBC-WS2812B | DigiKey | 25673106 | https://www.digikey.com/en/products/detail/xinglight/XL-5050RGBC-WS2812B/25673106 | LED:WS2812B | LED_SMD:LED_WS2812B_PLCC4_5.0x5.0mm_P3.2mm | https://cdn-shop.adafruit.com/datasheets/WS2812B.pdf | Firmware drives one WS2812 chain of 6 pixels (Pump1, Pump2, Valve1, Light1, Float, Sys) off GPIO10 via the led_strip RMT driver - NOT 4 discrete LED+resistor pairs as in the design doc's indicative BOM. Chain DIN->DOUT in firmware pixel order 0-5 (config.h *_LED_PIX defines).
Indicators | C10;C11;C12;C13;C14;C15 | 6 | Per-LED decoupling cap | 100nF 0402 | generic | - | DigiKey/Mouser | - | - | Device:C | Capacitor_SMD:C_0402_1005Metric | - | One per WS2812B per datasheet recommendation.
Indicators | R14 | 1 | LED data line series resistor | 330 ohm 0603 | generic | - | DigiKey/Mouser | - | - | Device:R | Resistor_SMD:R_0603_1608Metric | - | Between GPIO10 (LED_DATA_GPIO) and the first WS2812B DIN - standard practice to limit ringing/inrush on the data line.
Switches | SW1;SW2;SW3;SW4 | 4 | 3-position center-off switch (ON/AUTO/OFF) | SPDT ON-NONE-ON PC-pin | E-Switch | 100SP1T1B1M2QEH | DigiKey | - | https://www.digikey.com/en/products/detail/e-switch/100SP1T1B1M2QEH/ | Switch:SW_SPDT | Custom - THT PC-pin, panel bushing through enclosure faceplate (no standard KiCad footprint; build a 3-pad THT footprint per datasheet) | https://www.e-switch.com/product/100-series-miniature-toggle-switch/ | One per output channel (Pump1, Pump2, Valve1, Light1). Common -> 3V3, throw A -> SW_A GPIO, throw B -> SW_B GPIO. Firmware already configures SW_A/SW_B as GPIO_PULLDOWN_ONLY inputs, so no external pull resistors are needed - center/AUTO position reads both low.
Switches | SW5 | 1 | Reset / leak-lockout-clear pushbutton | Panel-actuated tactile | E-Switch | TL1220S1BBSG-RESET | DigiKey | 4029332 | https://www.digikey.com/en/products/detail/e-switch/TL1220S1BBSG-RESET/4029332 | Switch:SW_Push | Button_Switch_THT:SW_TL1220 | https://www.e-switch.com | Wired to RESET_BTN_GPIO, idle-high via internal pull-up (GPIO_PULLUP_ONLY in firmware, no external resistor needed). Firmware requires a 5s hold to clear the leak lockout and esp_restart().
Debug (optional - populate for bring-up only) | J8 | 1 | Debug/test-point header | 1x10 2.54mm pin header | generic | - | DigiKey/Mouser | - | - | Connector_Generic:Conn_01x10 | Connector_PinHeader_2.54mm:PinHeader_1x10_P2.54mm_Vertical | - | Breaks out the 9 DEBUG_GPIO_* task-timing test points (config.h) + GND for a logic analyzer during bring-up. Omit for a production board, or gate behind DEBUG_GPIO_ENABLE.

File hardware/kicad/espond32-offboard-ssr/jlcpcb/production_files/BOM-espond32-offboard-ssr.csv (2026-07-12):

Comment | Designator | Footprint | LCSC | Quantity
100nF | C12,C13,C14,C15,C16,C17,C18,C19,C2,C20,C3,C4 | C_0603_1608Metric | C14663 | 12
100uF | C8 | CP_Elec_6.3x7.7 | C15008 | 1
10K | R7 | R_0603_1608Metric | C25804 | 1
10k | R5 | R_0603_1608Metric | C25804 | 1
10nF | C10 | C_0603_1608Metric | C57112 | 1
10uF | C1,C5,C6,C7 | C_0603_1608Metric | C96446 | 4
1uF | C11 | C_0603_1608Metric | C15849 | 1
2.2k | R6 | R_0603_1608Metric | C4190 | 1
22 | R10,R11,R3,R4,R8,R9 | R_0603_1608Metric | C23345 | 6
220uF | C9 | CP_Elec_6.3x7.7 | C2036 | 1
330 | R12 | R_0603_1608Metric | C23138 | 1
33uH | L1 | L_Sunlord_SWPA6045S | C83451 | 1
5.1k | R1,R2 | R_0603_1608Metric | C23186 | 2
BAT54S | D4,D5,D6,D7,D8 | SOT-23 | C7420333 | 5
ESD9B5.0ST5G | D1,D2,D3 | D_SOD-923 | C111566 | 3
ESP32-S3-WROOM-1-N8 | U1 | ESP32-S3-WROOM-1 | C2913198 | 1
SS34 | D9 | D_SMA | C7420365 | 1
SW_Push | SW_GPIO0,SW_MCU_EN1,SW_RESET1 | SW_SPST_TL3342 | C2886894 | 3
USB_C_Receptacle_USB2.0_16P | J2 | USB_C_Receptacle_HRO_TYPE-C-31-M-12 | C165948 | 1
WS2812B-2020 | D_FLOAT1,D_LIGHT1,D_PUMP1,D_PUMP2,D_SYS1,D_VALVE1 | LED_WS2812B-2020_PLCC4_2.0x2.0mm | C965555 | 6
XL1509-3.3 | U2 | SOIC-8_3.9x4.9mm_P1.27mm | C2681226 | 1
Conn_01x02 | J3 | TerminalBlock_Phoenix_MPT-0,5-2-2.54_1x02_P2.54mm_Horizontal |  | 1
Conn_01x03 | J_VALVE1 | JST_XH_B3B-XH-A_1x03_P2.50mm_Vertical |  | 1
Conn_01x03 | J_PUMP1 | JST_XH_B3B-XH-A_1x03_P2.50mm_Vertical |  | 1
Conn_01x02 | J4 | TerminalBlock_Phoenix_MPT-0,5-2-2.54_1x02_P2.54mm_Horizontal |  | 1
Conn_01x02 | J7 | TerminalBlock_Phoenix_MPT-0,5-2-2.54_1x02_P2.54mm_Horizontal |  | 1
Conn_02x05_Odd_Even | J1 | PinHeader_2x05_P2.54mm_Vertical |  | 1
Conn_01x02 | J6 | TerminalBlock_Phoenix_MPT-0,5-2-2.54_1x02_P2.54mm_Horizontal |  | 1
Conn_01x03 | J_PUMP2 | JST_XH_B3B-XH-A_1x03_P2.50mm_Vertical |  | 1
Conn_01x02 | J5 | TerminalBlock_Phoenix_MPT-0,5-2-2.54_1x02_P2.54mm_Horizontal |  | 1
Conn_01x03 | J_LIGHT1 | JST_XH_B3B-XH-A_1x03_P2.50mm_Vertical |  | 1

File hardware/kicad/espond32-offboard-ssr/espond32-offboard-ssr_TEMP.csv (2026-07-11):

Reference | Qty | Value | DNP | Exclude from BOM | Exclude from Board | Footprint | Datasheet
C1,C5,C6,C7 | 4 | 10uF
C2,C3,C4,C12,C13,C14,C15,C16,C17,C18,C19,C20 | 12 | 100nF
C8 | 1 | 100uF
C9 | 1 | 220uF
C10 | 1 | 10nF
C11 | 1 | 1uF
D1,D2,D3 | 3 | ESD9B5.0ST5G |  |  |  | Diode_SMD:D_SOD-923 | https://www.onsemi.com/pub/Collateral/ESD9B-D.PDF
D4,D5,D11,D12,D13,D14,D15,D16,D17,D18 | 10 | D
D9 | 1 | SS34 |  |  |  | Diode_SMD:D_SMA | https://www.vishay.com/docs/88751/ss32.pdf
D_FLOAT1,D_LIGHT1,D_PUMP1,D_PUMP2,D_SYS1,D_VALVE1 | 6 | WS2812B-2020 |  |  |  | LED_SMD:LED_WS2812B-2020_PLCC4_2.0x2.0mm | https://cdn-shop.adafruit.com/product-files/4684/4684_WS2812B-2020_V1.3_EN.pdf
J1 | 1 | Conn_02x05_Odd_Even
J2 | 1 | USB_C_Receptacle_USB2.0_16P |  |  |  |  | https://www.usb.org/sites/default/files/documents/usb_type-c.zip
J3,J4,J5,J6,J7 | 5 | Conn_01x02
L1 | 1 | 33uH
R1,R2 | 2 | 5.1k
R3,R4,R8,R9,R10,R11 | 6 | 22
R5 | 1 | 10k
R6 | 1 | 2.2k
R7 | 1 | 10K
R12 | 1 | 330
SW_GPIO0,SW_MCU_EN1,SW_RESET1 | 3 | SW_Push
SW_LIGHT1,SW_PUMP1,SW_PUMP2,SW_VALVE1 | 4 | SW
U1 | 1 | ESP32-S3-WROOM-1-N8 |  |  |  | RF_Module:ESP32-S3-WROOM-1 | https://www.espressif.com/sites/default/files/documentation/esp32-s3-wroom-1_wroom-1u_datasheet_en.pdf
U2 | 1 | XL1509-3.3 |  |  |  | Package_SO:SOIC-8_3.9x4.9mm_P1.27mm | https://datasheet.lcsc.com/lcsc/1809050422_XLSEMI-XL1509-5-0E1_C61063.pdf

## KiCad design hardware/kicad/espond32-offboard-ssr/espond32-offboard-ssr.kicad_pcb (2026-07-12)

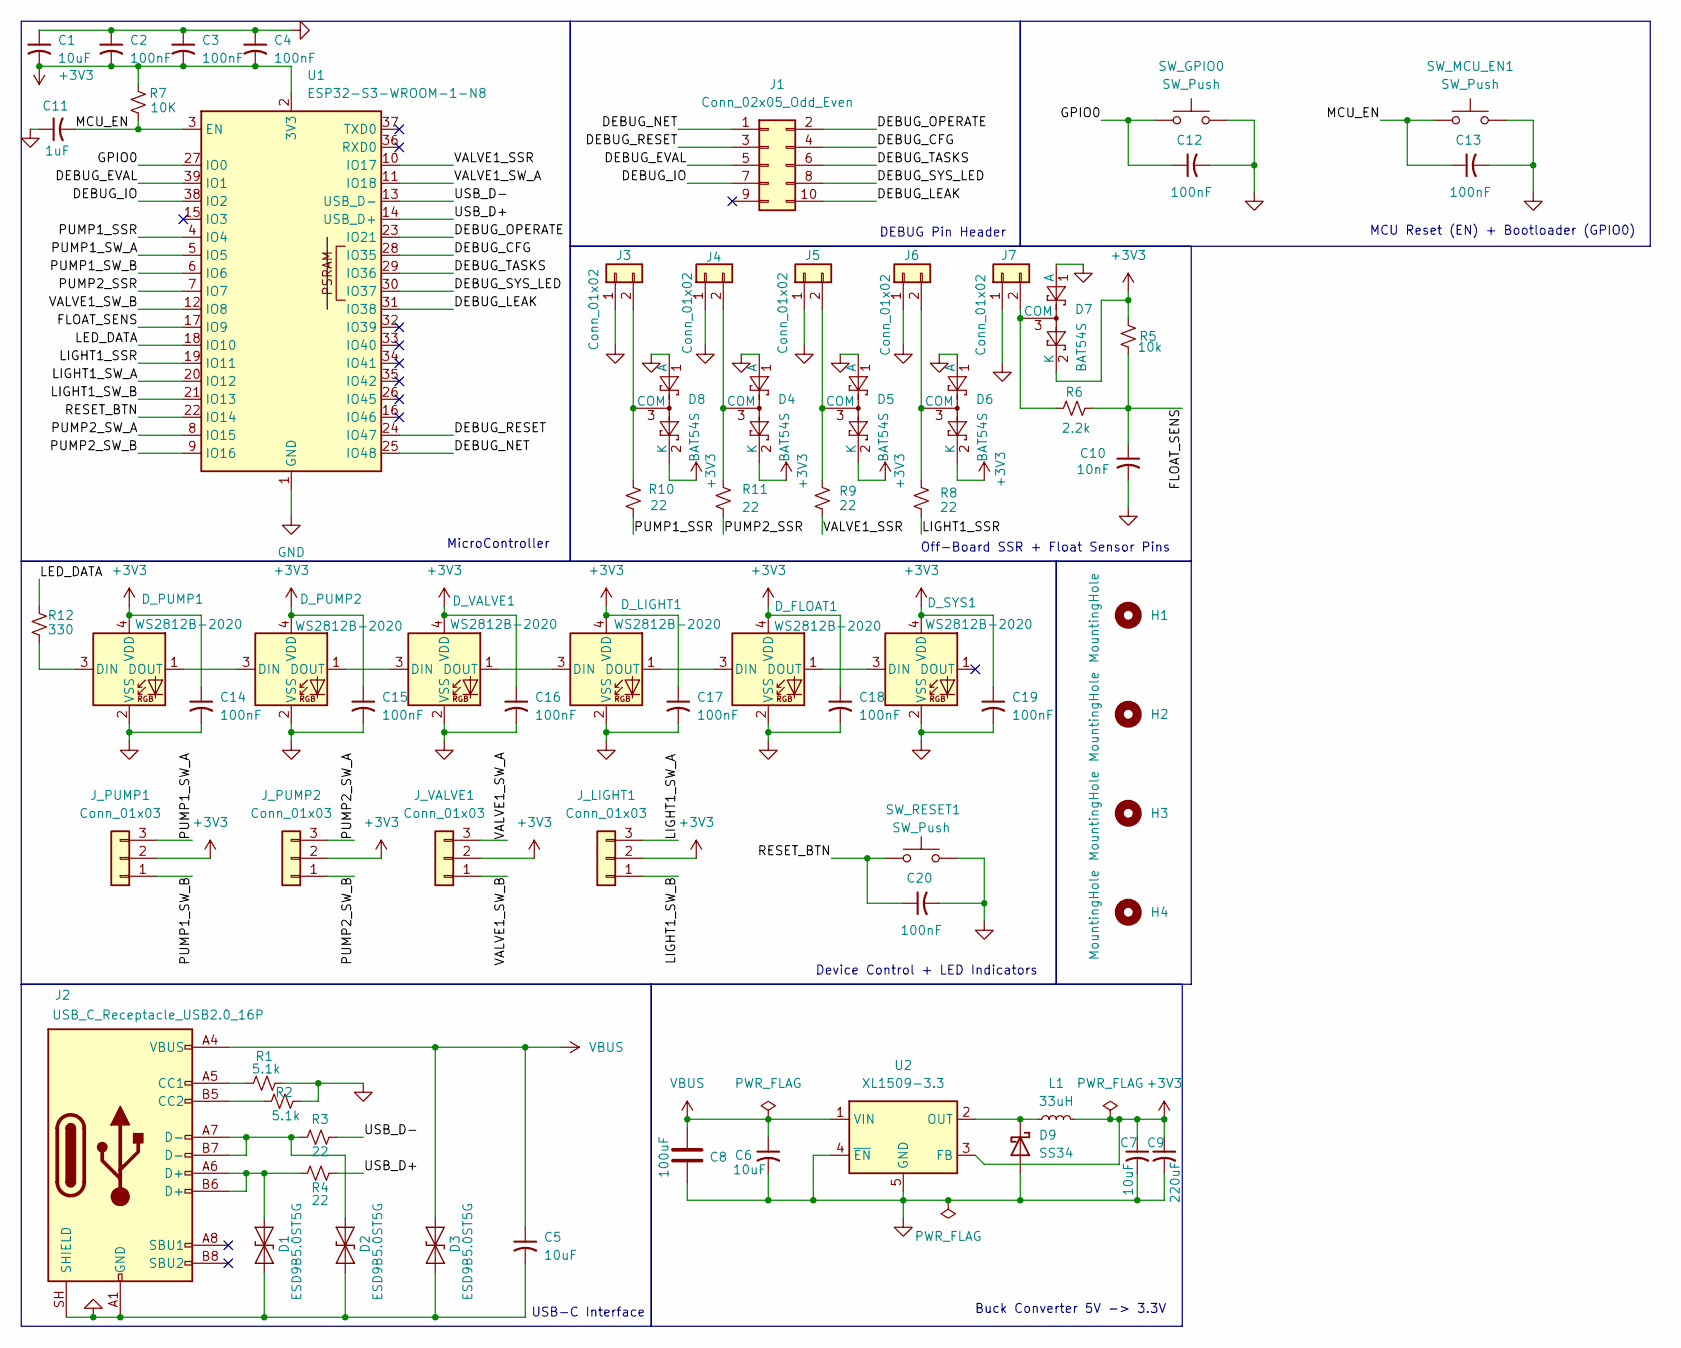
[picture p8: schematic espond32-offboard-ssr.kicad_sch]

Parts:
C1, C5, C6, C7: 10uF; C_0603_1608Metric
C2, C3, C4, C12, C13, C14, C15, C16, C17, C18, C19, C20: 100nF; C_0603_1608Metric
C8: 100uF; CP_Elec_6.3x7.7
C9: 220uF; CP_Elec_6.3x7.7
C10: 10nF; C_0603_1608Metric
C11: 1uF; C_0603_1608Metric
D1, D2, D3: ESD9B5.0ST5G; D_SOD-923
D4, D5, D6, D7, D8: BAT54S; SOT-23
D9: SS34; D_SMA
D_FLOAT1: WS2812B-2020; LED_WS2812B-2020_PLCC4_2.0x2.0mm
D_LIGHT1: WS2812B-2020; LED_WS2812B-2020_PLCC4_2.0x2.0mm
D_PUMP1, D_PUMP2: WS2812B-2020; LED_WS2812B-2020_PLCC4_2.0x2.0mm
D_SYS1: WS2812B-2020; LED_WS2812B-2020_PLCC4_2.0x2.0mm
D_VALVE1: WS2812B-2020; LED_WS2812B-2020_PLCC4_2.0x2.0mm
H1, H2, H3, H4: MountingHole; MountingHole_3.2mm_M3
J1: Conn_02x05_Odd_Even; PinHeader_2x05_P2.54mm_Vertical
J2: USB_C_Receptacle_USB2.0_16P; USB_C_Receptacle_HRO_TYPE-C-31-M-12
J3, J4, J5, J6, J7: Conn_01x02; TerminalBlock_Phoenix_MPT-0,5-2-2.54_1x02_P2.54mm_Horizontal
J_LIGHT1: Conn_01x03; JST_XH_B3B-XH-A_1x03_P2.50mm_Vertical
J_PUMP1, J_PUMP2: Conn_01x03; JST_XH_B3B-XH-A_1x03_P2.50mm_Vertical
J_VALVE1: Conn_01x03; JST_XH_B3B-XH-A_1x03_P2.50mm_Vertical
L1: 33uH; L_Sunlord_SWPA6045S
R1, R2: 5.1k; R_0603_1608Metric
R3, R4, R8, R9, R10, R11: 22; R_0603_1608Metric
R5: 10k; R_0603_1608Metric
R6: 2.2k; R_0603_1608Metric
R7: 10K; R_0603_1608Metric
R12: 330; R_0603_1608Metric
SW_GPIO0: SW_Push; SW_SPST_TL3342
SW_MCU_EN1: SW_Push; SW_SPST_TL3342
SW_RESET1: SW_Push; SW_SPST_TL3342
U1: ESP32-S3-WROOM-1-N8; ESP32-S3-WROOM-1
U2: XL1509-3.3; SOIC-8_3.9x4.9mm_P1.27mm

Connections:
+3V3: C1.2, C2.2, C3.2, C4.2, C7.1, C9.1, C14.1, C15.1, C16.1, C17.1, C18.1, C19.1, D4.2 (K), D5.2 (K), D6.2 (K), D7.2 (K), D8.2 (K), D_FLOAT1.4 (VDD), D_LIGHT1.4 (VDD), D_PUMP1.4 (VDD), D_PUMP2.4 (VDD), D_SYS1.4 (VDD), D_VALVE1.4 (VDD), J_LIGHT1.2, J_PUMP1.2, J_PUMP2.2, J_VALVE1.2, L1.2, R5.2, R7.2, U1.2 (3V3), U2.3 (FB)
/DEBUG_CFG: J1.4, U1.28 (IO35)
/DEBUG_EVAL: J1.5, U1.39 (IO1)
/DEBUG_IO: J1.7, U1.38 (IO2)
/DEBUG_LEAK: J1.10, U1.31 (IO38)
/DEBUG_NET: J1.1, U1.25 (IO48)
/DEBUG_OPERATE: J1.2, U1.23 (IO21)
/DEBUG_RESET: J1.3, U1.24 (IO47)
/DEBUG_SYS_LED: J1.8, U1.30 (IO37)
/DEBUG_TASKS: J1.6, U1.29 (IO36)
/FLOAT_SENS: C10.1, R5.1, R6.2, U1.17 (IO9)
/GPIO0: C12.1, SW_GPIO0.1, U1.27 (IO0)
/LED_DATA: R12.2, U1.18 (IO10)
/LIGHT1_SSR: R8.2, U1.19 (IO11)
/LIGHT1_SW_A: J_LIGHT1.3, U1.20 (IO12)
/LIGHT1_SW_B: J_LIGHT1.1, U1.21 (IO13)
/MCU_EN: C11.2, C13.1, R7.1, SW_MCU_EN1.1, U1.3 (EN)
/PUMP1_SSR: R10.2, U1.4 (IO4)
/PUMP1_SW_A: J_PUMP1.3, U1.5 (IO5)
/PUMP1_SW_B: J_PUMP1.1, U1.6 (IO6)
/PUMP2_SSR: R11.2, U1.7 (IO7)
/PUMP2_SW_A: J_PUMP2.3, U1.8 (IO15)
/PUMP2_SW_B: J_PUMP2.1, U1.9 (IO16)
/RESET_BTN: C20.1, SW_RESET1.1, U1.22 (IO14)
/USB_D+: R4.2, U1.14 (USB_D+)
/USB_D-: R3.2, U1.13 (USB_D-)
/VALVE1_SSR: R9.2, U1.10 (IO17)
/VALVE1_SW_A: J_VALVE1.3, U1.11 (IO18)
/VALVE1_SW_B: J_VALVE1.1, U1.12 (IO8)
GND: C1.1, C2.1, C3.1, C4.1, C5.2, C6.2, C7.2, C8.2, C9.2, C10.2, C11.1, C12.2, C13.2, C14.2, C15.2, C16.2, C17.2, C18.2, C19.2, C20.2, D1.2 (A2), D2.2 (A2), D3.2 (A2), D4.1 (A), D5.1 (A), D6.1 (A), D7.1 (A), D8.1 (A), D9.2 (A), D_FLOAT1.2 (VSS), D_LIGHT1.2 (VSS), D_PUMP1.2 (VSS), D_PUMP2.2 (VSS), D_SYS1.2 (VSS), D_VALVE1.2 (VSS), J2.A1 (GND), J2.A12 (GND), J2.B1 (GND), J2.B12 (GND), J2.SH (SHIELD), J3.1, J4.1, J5.1, J6.1, J7.1, R1.2, R2.2, SW_GPIO0.2, SW_MCU_EN1.2, SW_RESET1.2, U1.1 (GND), U1.40 (GND), U1.41 (GND), U2.4 (~EN), U2.5 (GND), U2.6 (GND), U2.7 (GND), U2.8 (GND)
unnamed: D1.1 (A1), J2.A6 (D+), J2.B6 (D+), R4.1
unnamed: D2.1 (A1), J2.A7 (D-), J2.B7 (D-), R3.1
unnamed: D4.3 (COM), J4.2, R11.1
unnamed: D5.3 (COM), J5.2, R9.1
unnamed: D6.3 (COM), J6.2, R8.1
unnamed: D7.3 (COM), J7.2, R6.1
unnamed: D8.3 (COM), J3.2, R10.1
unnamed: D9.1 (K), L1.1, U2.2 (OUT)
unnamed: D_FLOAT1.3 (DIN), D_LIGHT1.1 (DOUT)
unnamed: D_FLOAT1.1 (DOUT), D_SYS1.3 (DIN)
unnamed: D_LIGHT1.3 (DIN), D_VALVE1.1 (DOUT)
unnamed: D_PUMP1.3 (DIN), R12.1
unnamed: D_PUMP1.1 (DOUT), D_PUMP2.3 (DIN)
unnamed: D_PUMP2.1 (DOUT), D_VALVE1.3 (DIN)
unnamed: J2.A5 (CC1), R1.1
unnamed: J2.B5 (CC2), R2.1
VBUS: C5.1, C6.1, C8.1, D3.1 (A1), J2.A4 (VBUS), J2.A9 (VBUS), J2.B4 (VBUS), J2.B9 (VBUS), U2.1 (VIN)

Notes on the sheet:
USB-C Interface
MCU Reset (EN) + Bootloader (GPIO0)
Device Control + LED Indicators
Buck Converter 5V -> 3.3V
Off-Board SSR + Float Sensor Pins
DEBUG Pin Header
MicroController

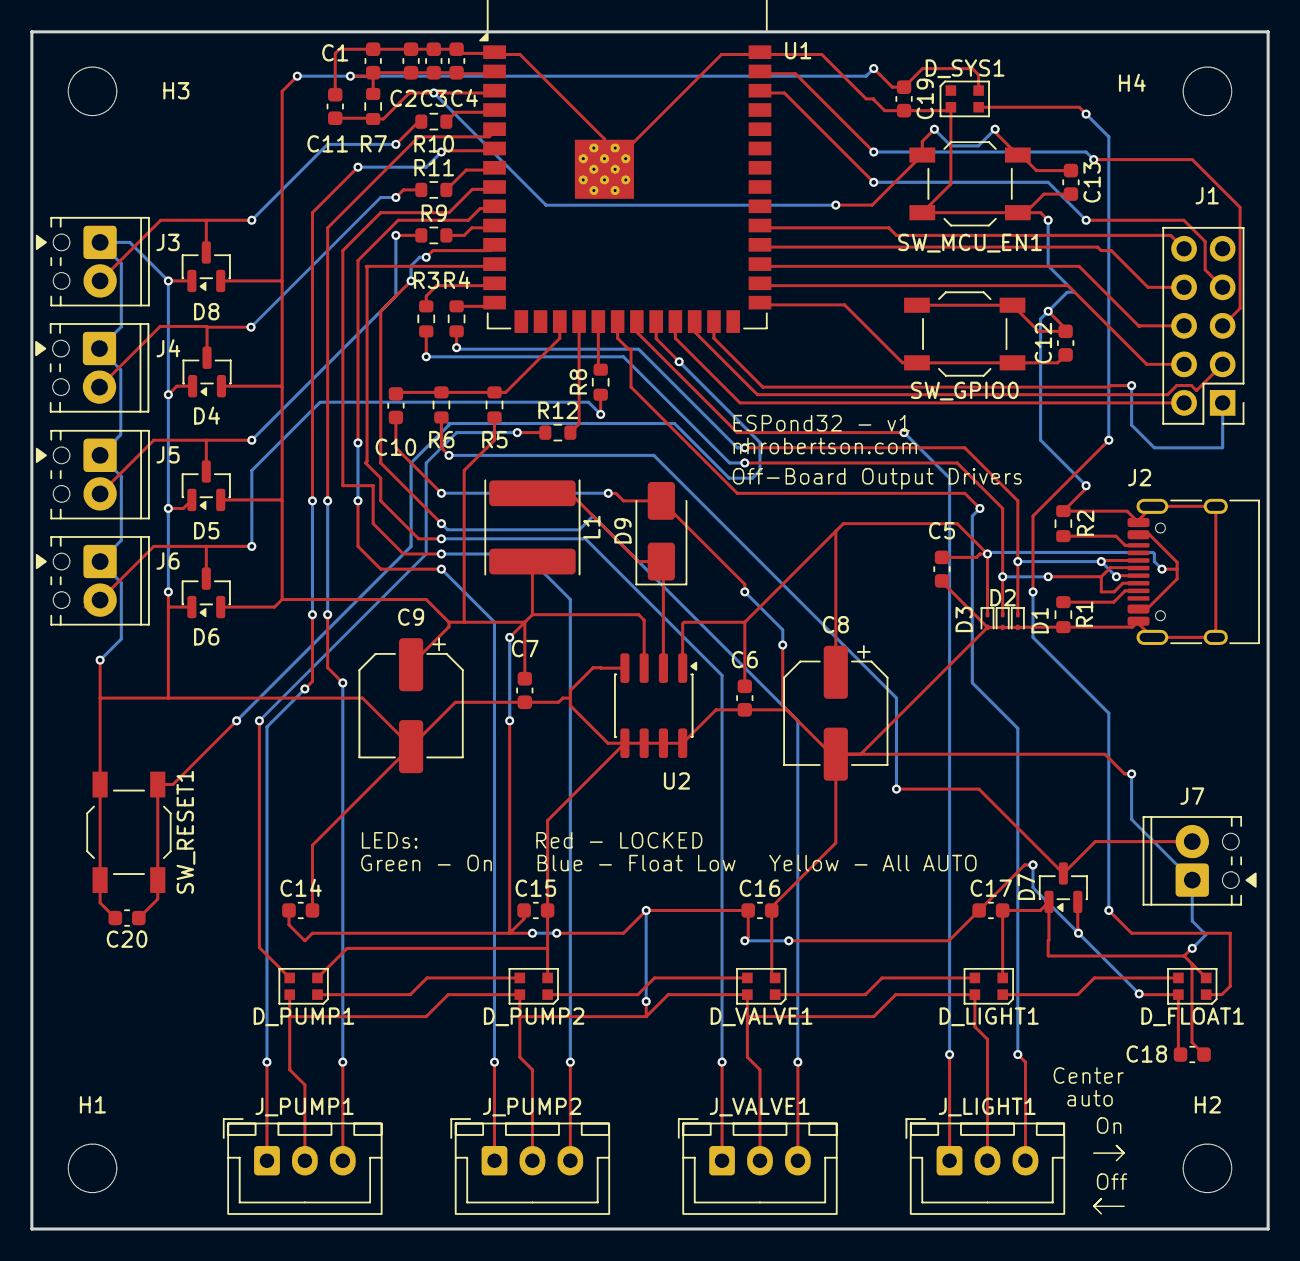
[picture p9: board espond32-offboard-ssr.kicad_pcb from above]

Board: 2 copper layers, 81.5 x 78.9 mm, 68 parts (0 on the bottom side), 47 nets.

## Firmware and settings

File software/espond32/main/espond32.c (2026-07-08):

/* ESPond32
  
   The ESPond32 is a IoT modular control unit to operate a series of pumps, a water valve, and monitoring water level

   It acts as the spirtual successor to the much less complex PondPi. This firmware is commited to the Public Domain for reuse under the GPL 3 license.
  
   Architectural Desicions:

   1. The main devices will all contain 3 GPIO Pins.
        - 2 Outputs to drive signals
        - 1 Input for configurable 3 state switch
   2. MQTT service to interact with a home server for Dashboard control instead of a on device hosted HTML webpage
   3. Drive signals take higher priority then Scheduabilty of said drive signals

   Hardware Requirements:

   The ESPond32 will have a custom pcb associated with this project, which preconnects input and output signals from the ESP32-WROOM-1

   For the inital version (v1), output signals to pumps and the valve will be driven by an external SSR, so a 3v3 gpio output signal is enough to statisfy
*/

#include <stdio.h>
#include "freertos/FreeRTOS.h"
#include "freertos/idf_additions.h"
#include "freertos/task.h"
#include "driver/gpio.h"
#include "esp_log.h"
#include "led_strip.h"
#include "nvs.h"
#include "sdkconfig.h"
#include "device.h"
#include "models.h"
#include "nvs_flash.h"
#include "filesystem.h"
#include "tasks.h"
#include "network.h"
#include "debug_gpio.h"

static const char *TAG = "espond32";

void app_main(void)
{
    ESP_LOGI(TAG, "espond32 starting up");

    esp_err_t err;
    err = nvs_flash_init();
    if (err == ESP_ERR_NVS_NO_FREE_PAGES || err == ESP_ERR_NVS_NEW_VERSION_FOUND) {
      ESP_ERROR_CHECK(nvs_flash_erase());
      err = nvs_flash_init();
    }
    if (err != ESP_OK) {
      ESP_LOGE(TAG, "nvs_flash_init failed: %s", esp_err_to_name(err));
    }

    cfg_buff_mutex = xSemaphoreCreateMutex();
    cfg_change_mutex = xSemaphoreCreateMutex();
    ovr_change_mutex = xSemaphoreCreateMutex();
    lockout_change_mutex = xSemaphoreCreateMutex();

    g_events = xEventGroupCreate();
    s_net_events = xEventGroupCreate();

    leak_check_mutex = xSemaphoreCreateMutex();

    debug_gpio_init();

    cfg_load(&g_espond_cfg);
    nvs_load_lockout(&lockout);

    devices_init();
    
    //Core 1
    xTaskCreatePinnedToCore(task_check_io, "io", 4096, NULL, 6, NULL, 1);
    xTaskCreatePinnedToCore(task_evaluate_cfg, "eval", 4096, NULL, 8, NULL, 1);
    xTaskCreatePinnedToCore(task_operate, "operate", 4096, NULL, 7, &operate_handle, 1);
    xTaskCreatePinnedToCore(task_check_leak, "leak", 4096, NULL, 5, NULL, 1);
    xTaskCreatePinnedToCore(task_check_for_reset, "reset", 4096, NULL, 10, NULL, 1);
    xTaskCreatePinnedToCore(task_listen_for_task_event, "tasks", 2048, NULL, 4, &task_handle, 1);
    xTaskCreatePinnedToCore(task_set_sys_light, "sys_led", 4096, NULL, 3, NULL, 1);
    
    //Core 0
    xTaskCreatePinnedToCore(task_check_cfg, "cfg", 4096, NULL, 4, NULL, 0);
    xTaskCreatePinnedToCore(task_net_manager, "net", 8196, NULL, 5, NULL, 0);

    ESP_LOGI(TAG, "startup complete, all tasks running");
}

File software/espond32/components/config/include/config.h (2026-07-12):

#ifndef CONFIG_H
#define CONFIG_H

#define NUM_OUTPUTS       4
#define NUM_INPUTS        1
#define NUM_DEVICES       (NUM_OUTPUTS + NUM_INPUTS)


#define NUM_PUMPS         2
#define NUM_VALVES        1
#define NUM_LIGHT         1
#define NUM_FLOAT         1

#define NUM_LEDS          (NUM_DEVICES + 1) //1 - Pump 1, 2 - Pump 2, 3 - Valve 1, 4 - Light 1, 5 - Float Sensor

#define DEBOUNCE_SAMPLES      5
#define MAX_FILL_MIN          25  //Max continuous fill duration before lockout (stuck float failsafe)
//GPIO Definitions
#define PUMP1_SSR_GPIO        GPIO_NUM_4
#define PUMP1_SW_A_GPIO       GPIO_NUM_5
#define PUMP1_SW_B_GPIO       GPIO_NUM_6
#define PUMP1_LED_PIX         0

#define PUMP2_SSR_GPIO        GPIO_NUM_7
#define PUMP2_SW_A_GPIO       GPIO_NUM_15
#define PUMP2_SW_B_GPIO       GPIO_NUM_16
#define PUMP2_LED_PIX         1

#define VALVE1_SSR_GPIO       GPIO_NUM_17
#define VALVE1_SW_A_GPIO      GPIO_NUM_18
#define VALVE1_SW_B_GPIO      GPIO_NUM_8
#define VALVE1_LED_PIX        2

#define LIGHT1_SSR_GPIO       GPIO_NUM_11
#define LIGHT1_SW_A_GPIO      GPIO_NUM_12
#define LIGHT1_SW_B_GPIO      GPIO_NUM_13
#define LIGHT1_LED_PIX        3

#define FLOAT1_SENS_GPIO      GPIO_NUM_9
#define FLOAT1_LED_PIX        4


#define LED_DATA_GPIO         GPIO_NUM_10

#define RESET_BTN_GPIO        GPIO_NUM_14

#define SYS_LED_PIX           5


#define DEBUG_INDEPTH_LOG     1
#define DEBUG_GPIO_ENABLE     1

#define DEBUG_GPIO_OPERATE    GPIO_NUM_21   //task_operate      (Core 1, 50ms)
#define DEBUG_GPIO_EVAL       GPIO_NUM_1    //task_evaluate_cfg (Core 1, 250ms)
#define DEBUG_GPIO_IO         GPIO_NUM_2    //task_check_io     (Core 1, 10ms)
#define DEBUG_GPIO_LEAK       GPIO_NUM_38   //task_check_leak   (Core 1, 10ms)
#define DEBUG_GPIO_RESET      GPIO_NUM_47   //task_check_for_reset (Core 1, 50ms)
#define DEBUG_GPIO_NET        GPIO_NUM_48   //task_net_manager  (Core 0, event-driven)
#define DEBUG_GPIO_CFG        GPIO_NUM_35   //task_check_cfg    (Core 0, event-driven)
#define DEBUG_GPIO_TASKS      GPIO_NUM_36   //task_listen_for_task_event (Core 1, event-driven)
#define DEBUG_GPIO_SYS_LED    GPIO_NUM_37   //task_set_sys_light (Core 1, 1000ms)


#endif //CONFIG_H

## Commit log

2026-06-17 First commitment
    [espond32.kicad_pcb, espond32.kicad_sch]
2026-06-26 Lots of work on I/O and LED - device initalization base almost done
2026-07-05 Added More Device Control + Date and Time get_local_time()
2026-07-07 Added float stuff, reset button, and more
2026-07-08 Potentially working firmware, LOGE added by claude, DEBUG signals added by claude, audited multiple times and patched minor bugs
    [config.h, espond32.c]
2026-07-08 Firmware testing in progress, claude developed Mosquitto based MQTT web client to be ran on Raspberry Pi 3
2026-07-08 Finalized webpage + Firmware, tested seemingly working, added two kicad projects for Hardware
    [espond32-offboard-ssr.kicad_pcb, espond32-offboard-ssr.kicad_sch, espond32-onboard-ssr.kicad_pcb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]
2026-07-11 Off-Board SSR hardware may be done...
    [BOM-espond32-offboard-ssr.csv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]
2026-07-12 Final tweaks before DevKitC deployment
    [espond32-offboard-ssr.kicad_pcb]
2026-07-12 updated hardware
    [BOM-espond32-offboard-ssr.csv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]
